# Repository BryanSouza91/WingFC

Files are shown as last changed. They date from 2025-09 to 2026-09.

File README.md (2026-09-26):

# WingFC

> [!WARNING]
> ### ⚠️ REPOSITORY ARCHIVED & SUPERSEDED
> This original TinyGo implementation of WingFC has been archived and is preserved for historical reference.
>
> Active development has transitioned into two dedicated, first-class repositories within the **Ferrox-RC** ecosystem:
> - 🦀 **Firmware:** [**ferrox-rc/wingfc-rs**](https://github.com/ferrox-rc/wingfc-rs) — High-performance, zero-latency bare-metal Rust flight controller firmware for sub-250g wings and UAVs.
> - ⚡ **Hardware:** [**ferrox-rc/wingfc-hardware**](https://github.com/ferrox-rc/wingfc-hardware) — KiCad schematics, 4-layer PCB layouts, 3D mechanical models, and carrier board designs.

### Historical Version 0.3.0 (TinyGo Prototype)

WingFC is a specialized open-source embedded flight controller designed specifically for the rapidly growing sub-250g flying wing FPV (First-Person-View) market. The project's core mission is to provide a reliable, user-friendly, and highly customizable solution for hobbyists and enthusiasts building ultra-lightweight Unmanned Aerial Vehicles (UAVs).

The emphasis on the sub-250g weight class is a direct response to a patchwork of international regulations. Many aviation authorities worldwide, including the Federal Aviation Administration (FAA) in the U.S. and the European Union Aviation Safety Agency (EASA), have established a 250-gram weight threshold as a key regulatory distinction. UAVs below this weight are often considered a lower risk and are exempt from stricter rules, such as mandatory registration, Remote ID requirements, or more complex pilot licensing. By focusing on this market segment, WingFC enables hobbyists to build and fly FPV aircraft that can be legally operated in more places and with fewer bureaucratic hurdles, significantly lowering the barrier to entry for beginners and experienced pilots alike.

Powered by TinyGo, a Go compiler for microcontrollers, WingFC offers a robust and stable software platform. The project provides essential flight control features for elevon-equipped fixed-wing aircraft, including:

- **Stabilization Modes**: Offers flight stabilization to assist pilots, particularly for smooth, cinematic FPV footage and relaxed cruising.

- **Mixing**: Handles the complex mixing of aileron and elevator inputs for a fixed-wing flying wing platform, simplifying the aircraft's setup.

- **Safety Features**: Incorporates failsafe mechanisms to protect the aircraft and others in the event of signal loss.

- **Receiver Protocol Support**: Ensures broad compatibility with popular FPV communication standards, including FlySky's iBus, TBS's CRSF, and the open-source ELRS protocol, which is highly valued for its long-range capabilities and low latency in the FPV community.

The flight controller is engineered for a seamless integration into FPV flying wing airframes like the ZOHD Dart 250G or Alight Wing Aeronautics Flik, a prominent model in this market. The hardware's choice of the Seeed Studio Xiao nRF52840 Sense with an onboard IMU aligns with the project's goal of creating a compact, lightweight, and high-performance control system for these specific FPV drones.

## Getting Started

These instructions will get you a copy of the project up and running on your local machine for development and testing purposes. See deployment for notes on how to deploy the project on a live system.

### Prerequisites

What things you need to install the software and how to install them

```
- Go (TinyGo)
- Supported microcontroller (see docs)
```

### Installing

[Download source code](https://github.com/BryanSouza91/WingFC/releases/tag/v0.3.0)
Extract source code then navigate to the top directory of the source.
```
cd firmware/src
```

Plug in WingFC board via USB-C 

When the filesystem shows up on your computer, flash firmware to your board

```
tinygo flash -target=xiao-ble -tags=<ibus,crsf> firmware/src
```

## Deployment

Add additional notes about how to deploy this on a live system

- Flash the firmware to your supported board
- Connect servos and sensors as described
- Power up and calibrate according to instructions

## Built With

### Software
• [TinyGo](https://tinygo.org/) - Go compiler for microcontrollers  
• [Go](https://golang.org/) - Language
### Hardware
• [Seeed Studio Xiao nrf52840 Sense](https://wiki.seeedstudio.com/XIAO_BLE/) - Xiao nrf52840 Sense microcontroller with onboard IMU

## Supported Receiver Protocols

WingFC supports multiple RC receiver protocols for maximum compatibility:

- **iBus** (FlySky): Supports up to 18 channels (FS-A8S, FS-iA6B)
- **CRSF** (TBS): Supports up to 16 channels
- **ELRS** (open-source): Supports up to 16 channels (uses CRSF build)

## Contributing

Please read [CONTRIBUTING.md](https://github.com/BryanSouza91/WingFC/CONTRIBUTING.md) for details on our code of conduct, and the process for submitting pull requests to us.

## Versioning

We use [SemVer](http://semver.org/) for versioning. For the versions available, see the [tags on this repository](https://github.com/BryanSouza91/WingFC/tags).

## Authors

• Bryan Souza - Initial work - [BryanSouza91](https://github.com/BryanSouza91)
• truglodite - CRSF/ELRS finalization, feature additions - [truglodite](https://github.com/truglodite)

See also the list of [contributors](https://github.com/BryanSouza91/WingFC/contributors) who participated in this project.

## License

This project is licensed under the MIT License - see the [LICENSE](https://github.com/BryanSouza91/WingFC/blob/main/LICENSE) file for details

## Acknowledgments

• Hat tip to anyone whose code was used  
• Inspiration from open-source flight controllers  
• TinyGo and Go communities

## Footer

[GitHub Homepage](https://github.com/)
# WingFC

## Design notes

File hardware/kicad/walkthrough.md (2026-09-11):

# WingFC Flight Controller Hardware Redesign Walkthrough

## Summary of Revisions

Based on feedback, the WingFC flight controller PCB has been comprehensively updated in [`hardware/kicad/`](file:///home/bryansouza/Repos/WingFC/hardware/kicad):

1. **Edge-Mounted North-Facing USB-C Port**:
   - Re-oriented the **Seeed Studio XIAO nRF52840 Sense Plus** (`U1`) by 180° so the USB-C receptacle faces North towards the front edge of the aircraft.
   - Added a dedicated **$12.0\,\text{mm} \times 2.0\,\text{mm}$ recessed access notch** on the front edge of the carrier board.
   - The USB-C connector receptacle now overhangs into free air by $\sim 3.5\,\text{mm}$, ensuring any standard USB-C cable plugs in without mechanical collision against the PCB.

2. **10 Actuator Channels (2 ESCs + 8 Servos)**:
   - Expanded the schematic ([`WingFC.kicad_sch`](file:///home/bryansouza/Repos/WingFC/hardware/kicad/WingFC.kicad_sch)) and netlist ([`WingFC.net`](file:///home/bryansouza/Repos/WingFC/hardware/kicad/WingFC.net)) from 7 channels to **10 channels total**:
     - **`ESC1`** (Motor 1): `D3` (`P0.29`, `PWM0` Ch 0)
     - **`ESC2`** (Motor 2 / Differential Thrust): `D8` (`P1.13`, `PWM0` Ch 1)
     - **`S1`** (Servo 1 - Left Elevon / Aileron): `D0` (`P0.02`, `PWM1` Ch 0)
     - **`S2`** (Servo 2 - Right Elevon / Elevator): `D1` (`P0.03`, `PWM1` Ch 1)
     - **`S3`** (Servo 3 - Rudder / V-Tail): `D2` (`P0.28`, `PWM1` Ch 2)
     - **`S4`** (Servo 4 - Flap / Aux): `D9` (`P1.14`, `PWM1` Ch 3)
     - **`S5`** (Servo 5 - Aux / Pan): `D10` (`P1.15`, `PWM2` Ch 0)
     - **`S6`** (Servo 6 - Flap / Tilt): `D11` (`P0.15`, `PWM2` Ch 1)
     - **`S7`** (Servo 7 - Aux / Arm): `D12` (`P0.19`, `PWM2` Ch 2)
     - **`S8`** (Servo 8 - Payload / Drop): `D13` (`P1.01`, `PWM2` Ch 3)
   - Arranged in a continuous $3 \times 10$ rear block (Signal / +5V / GND) with $2.54\,\text{mm}$ pitch.
   - Silkscreen labels rotated 90° to eliminate text overlap, with clear `S`, `+`, `-` row legends on both flanks.

3. **Outward-Facing JST-SH Connectors**:
   - Rotated both horizontal JST-SH connectors 180°:
     - **`J_RC`** (4-pin JST-SH) on the West (left) edge now has its plug insertion opening facing outward to the left.
     - **`J_GPS`** (6-pin JST-SH) on the East (right) edge now has its plug insertion opening facing outward to the right.
   - Solder pads sit securely on the board copper, while mating cables insert horizontally from outside the board.

4. **Optimized Compact Dimensions**:
   - Target mounting pattern: **$25.5 \times 25.5\,\text{mm}$ M2 pattern** (`H1`..`H4` at $\pm 12.75\,\text{mm}$ from center $(150, 100)$).
   - Board dimensions: **$34.0\,\text{mm}$ wide $\times 40.0\,\text{mm}$ long**.
   - Shortened board length from $41.5\,\text{mm}$ down to $40.0\,\text{mm}$ while fitting all 10 actuator channels.

---

## 3D Board Visualizations

````carousel
![WingFC Top 3D View](/home/bryansouza/.gemini/antigravity/brain/f0d6860b-f0ef-4c42-afec-4011cef9209b/WingFC_3D_top.png)
<!-- slide -->
![WingFC Isometric 3D View](/home/bryansouza/.gemini/antigravity/brain/f0d6860b-f0ef-4c42-afec-4011cef9209b/WingFC_3D_iso.png)
<!-- slide -->
![WingFC Bottom 3D View](/home/bryansouza/.gemini/antigravity/brain/f0d6860b-f0ef-4c42-afec-4011cef9209b/WingFC_3D_bottom.png)
````

---

## Hardware Specifications Table

| Subsystem | Component | Footprint / Package | Location / Layer | Details |
| :--- | :--- | :--- | :--- | :--- |
| **MCU & IMU** | Seeed XIAO nRF52840 Sense Plus | `KiCAD:XIAO-nRF52840-Plus-SMD` | `F.Cu` (Top Center) | 64MHz Cortex-M4F, BLE 5.0, 6-DoF IMU, PDM mic |
| **Actuators** | 10x 1x03 Pin Headers | `Connector_PinHeader_2.54mm` | `F.Cu` (Rear Shelf) | 2x ESCs (`ESC1`, `ESC2`) + 8x Servos (`S1`..`S8`) |
| **RC Receiver** | 4-Pin JST-SH Horizontal | `Connector_JST:JST_SH_SM04B...` | `F.Cu` (West Edge) | 5V, GND, UARTE0 TX/RX (CRSF / iBUS) |
| **GPS & Compass** | 6-Pin JST-SH Horizontal | `Connector_JST:JST_SH_SM06B...` | `F.Cu` (East Edge) | 5V, GND, UARTE1 TX/RX, TWISPI1 SDA/SCL |
| **BEC Power** | Monolithic Power MP2315 | `Package_TO_SOT_SMD:TSOT-23-8` | `B.Cu` (Bottom) | 5V / 2A synchronous step-down (up to 24V in) |
| **Inductor** | Bourns SRN4018 4.7µH | `Inductor_SMD:L_Bourns_SRN4018` | `B.Cu` (Bottom) | Shielded power inductor |
| **Barometer** | Infineon DPS310 | `Package_LGA:Infineon_PG-VLGA-8-1` | `B.Cu` (Bottom) | High-precision pressure sensor on TWISPI1 |
| **Protection** | Littlefuse SMAJ5.0A TVS | `Diode_SMD:D_SMA` | `B.Cu` (Bottom) | 400W transient voltage suppressor on +5V rail |
| **MCU Isolation** | Diodes Inc B0520W Schottky | `Diode_SMD:D_SOD-123` | `B.Cu` (Bottom) | Reverse current protection to +5V_MCU with 10µF cap |
| **Battery Sensing**| 100k / 10k Divider + 100nF | `0603 Metric` | `B.Cu` (Bottom Left) | 11:1 attenuation to SAADC AIN7 (`D16` / `P0.31`) |
| **Mounting** | 4x M2 Holes | `MountingHole_2.2mm_M2` | All Layers | Exact $25.5 \times 25.5\,\text{mm}$ square whoop pitch |

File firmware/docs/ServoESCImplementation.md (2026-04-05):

# WingFC Servo & ESC Control Implementation Report

## Executive Summary
Implemented multi-servo airframe support by upgrading from 2-servo control to 6-servo control with airframe-specific mixing. System now supports elevon flying wings, T-tail configurations, and V-tail configurations through configurable mixer logic.

---

## Architecture Overview

### Servo Output Strategy
- **Servo 1**: Primary aileron control (left elevon / left aileron)
- **Servo 2**: Primary elevator control (right elevon / elevator)
- **Servo 4**: Rudder/V-tail secondary mixing
- **Servo 5**: Secondary aileron (for dual-aileron airframes)
- **Servo 6**: Future expansion (aux control)
- **ESC**: Throttle control (separate PWM peripheral)

### Control Flow
```
RC Input → Kalman Filter (6DoF) → PID Controllers (3-axis)
  ↓
Mixer (airframe-specific) → Servo outputs (1,2,4,5,6)
  ↓
setAllServos() → PWM Hardware → Physical Servos
```

---

## Hardware Configuration Changes

### FC_Hardware Struct Updates
Added six PWM channel ID storage and pin mappings:

```go
type FC_Hardware struct {
	// ... existing fields ...
	pwmCh1, pwmCh2, pwmCh3, pwmCh4, pwmCh5, pwmCh6 uint8  // Channel IDs
	PWM_CH1_PIN machine.Pin  // Aileron Servo
	PWM_CH2_PIN machine.Pin  // Elevator Servo
	PWM_CH3_PIN machine.Pin  // ESC
	PWM_CH4_PIN machine.Pin  // Rudder/V-tail
	PWM_CH5_PIN machine.Pin  // Aileron 2
	PWM_CH6_PIN machine.Pin  // Future use
}
```

### PWM Peripheral Assignment
- **PWM0 (ServoPWM)**: Channels 1, 2, 4, 5, 6 @ 50Hz or 100Hz (servo frequency)
- **PWM1 (ESCPWM)**: Channel 3 @ 50Hz or 400Hz (ESC frequency, configurable)

### Pin Configuration in hardware.go
Each channel (1-6) is configured with retry logic (5 attempts, 100ms intervals):

```go
// Example: Channel configuration pattern
for retries := 0; retries < 5; retries++ {
	ch, err := hw.ServoPWM.Channel(hw.PWM_CH1_PIN)
	if err != nil {
		if retries < 4 {
			time.Sleep(100 * time.Millisecond)
			continue
		}
		return fmt.Errorf("servo PWM channel 1 failed after retries: %w", err)
	}
	hw.pwmCh1 = ch
	break
}
```

---

## Configuration Updates (config.go)

### Airframe Selection
```go
const (
	AIRFRAME_ELEVON = iota
	AIRFRAME_SINGLE_AILERON_T_TAIL
	AIRFRAME_DUAL_AILERON_T_TAIL
	AIRFRAME_SINGLE_AILERON_V_TAIL
	AIRFRAME_DUAL_AILERON_V_TAIL
)
const AIRCRAFT_TYPE = AIRFRAME_ELEVON
```

### Servo Travel Limits
Each servo has configurable min/max pulse widths:
```go
const (
	SERVO1_MIN, SERVO1_MAX = 1100, 1900  // µs
	SERVO2_MIN, SERVO2_MAX = 1100, 1900
	SERVO4_MIN, SERVO4_MAX = 1100, 1900
	SERVO5_MIN, SERVO5_MAX = 1100, 1900
	SERVO6_MIN, SERVO6_MAX = 1100, 1900
)
```

### Servo Reversals
Per-servo reversible output:
```go
const (
	SERVO1_REVERSE = false
	SERVO2_REVERSE = false
	SERVO4_REVERSE = false
	SERVO5_REVERSE = false
	SERVO6_REVERSE = false
)
```

### Yaw Control
```go
const (
	YawChannel = 3  // CH4
	MAX_YAW_RATE_DEG = 100
	yP, yI, yD float32 = 0.5, 0.05, 0.01
)
```

---

## Mixer Implementation (mixer.go - New File)

### ApplyMixer Function
Central airframe configuration logic:

```go
func ApplyMixer(pitchOutput, rollOutput, yawOutput float32) 
	(servo1, servo2, servo4, servo5, servo6 float32)
```

### Supported Configurations

**1. Elevon (Flying Wing) - Default**
```
Left Elevon = Roll + Pitch
Right Elevon = -Roll + Pitch
Yaw servo = Raw yaw output
```

**2. Single Aileron T-Tail**
```
Aileron = Roll
Elevator = Pitch
Rudder = Yaw
```

**3. Dual Aileron T-Tail**
```
Left Aileron = Roll
Elevator = Pitch
Rudder = Yaw
Right Aileron = -Roll
```

**4. Single Aileron V-Tail**
```
Aileron = Roll
Right Surface = Pitch + Yaw
Left Surface = Pitch - Yaw
```

**5. Dual Aileron V-Tail**
```
Left Aileron = Roll
Right Surface = Pitch + Yaw
Left Surface = Pitch - Yaw
Right Aileron = -Roll
```

### Servo Reversals
Applied after mixing:
```go
if SERVO1_REVERSE {
	servo1 = SERVO1_MIN + SERVO1_MAX - servo1
}
// ... same for servos 2, 4, 5, 6
```

---

## Control Loop Updates (main.go)

### Global Variables Added
```go
var (
	yawPID *PIDController
	desiredYawRate float32
)
```

### Hardware Initialization
```go
hw = &FC_Hardware{
	// ... existing ...
	PWM_CH1_PIN: machine.D0,
	PWM_CH2_PIN: machine.D1,
	PWM_CH3_PIN: machine.D2,
	PWM_CH4_PIN: machine.D3,  // New
	PWM_CH5_PIN: machine.D4,  // New
	PWM_CH6_PIN: machine.D5,  // New
}
```

### PID Initialization
```go
yawPID = NewPIDController(yP, yI, yD)
```

### Stabilized Flight Loop
Three-axis control with airframe-specific mixing:

1. **Sensor Fusion**
   ```go
   kf.Predict(imuData.GyroX, imuData.GyroY, imuData.GyroZ)
   kf.Update(imuData.Pitch, imuData.Roll)
   ```

2. **RC Input Mapping**
   ```go
   desiredPitchRate = mapRange(Channels[ElevatorChannel], ...)
   desiredRollRate = mapRange(Channels[AileronChannel], ...)
   desiredYawRate = mapRange(Channels[YawChannel], ...)
   ```

3. **PID Control**
   ```go
   pitchOutput = pitchPID.Update(pitchError, dt) * PID_WEIGHT
   rollOutput = rollPID.Update(rollError, dt) * PID_WEIGHT
   yawOutput = yawPID.Update(yawError, dt) * PID_WEIGHT
   ```

4. **Airframe Mixing**
   ```go
   servo1, servo2, servo4, servo5, servo6 := ApplyMixer(pitchOutput, rollOutput, yawOutput)
   ```

5. **Output Mapping & Constraints**
   ```go
   servo1 = mapRange(servo1, -MAX_ROLL_RATE, MAX_ROLL_RATE, MIN_PULSE_WIDTH_US, MAX_PULSE_WIDTH_US)
   servo1 = constrain(servo1, SERVO1_MIN, SERVO1_MAX)
   // ... for all servos
   ```

6. **Hardware Output**
   ```go
   setAllServos(uint32(servo1), uint32(servo2), uint32(servo4), uint32(servo5), uint32(servo6))
   ```

---

## Helper Functions (helpers.go)

### New: setAllServos()
Controls all six servo channels with PWM duty cycle calculation:

```go
func setAllServos(servo1, servo2, servo4, servo5, servo6 uint32) {
	if hw == nil || hw.ServoPWM == nil {
		return
	}
	
	top_value := hw.ServoPWM.Top()
	
	// Calculate duty cycle for each servo
	// duty = (pulse_width_µs * 1000 * PWM_TOP) / ServoPeriod
	duty1 := uint32(uint64(servo1) * 1000 * uint64(top_value) / uint64(hw.ServoPeriod))
	hw.ServoPWM.Set(hw.pwmCh1, duty1)
	
	// ... repeat for servo2, servo4, servo5, servo6
}
```

### Legacy: setServo()
Preserved for backward compatibility, wraps setAllServos():

```go
func setServo(leftPulse, rightPulse uint32) {
	setAllServos(leftPulse, rightPulse, NEUTRAL_RX_VALUE, NEUTRAL_RX_VALUE, NEUTRAL_RX_VALUE)
}
```

### setESC()
Unchanged - remains separate PWM peripheral (PWM1)

---

## Kalman Filter (kalman.go)

### 3x3 Matrix Implementation
Full 3-axis attitude estimation:

```go
type KalmanFilter struct {
	X *Matrix3x1  // State: [pitch, roll, yaw]
	P *Matrix3x3  // Covariance
	Q *Matrix3x3  // Process noise
	R *Matrix2x2  // Measurement noise (accel: pitch, roll)
	F *Matrix3x3  // State transition
	H *Matrix3x2  // Observation matrix (3 states → 2 measurements)
	dt float32
}
```

### State Propagation
All three axes predicted from gyroscope:
```go
func (kf *KalmanFilter) Predict(gyroX, gyroY, gyroZ float32) {
	gyroVector.Set(0, 0, gyroY*kf.dt)   // Pitch rate
	gyroVector.Set(1, 0, gyroX*kf.dt)   // Roll rate
	gyroVector.Set(2, 0, gyroZ*kf.dt)   // Yaw rate
	kf.X = kf.X.Add(gyroVector)
	// P_pred = F*P*F^T + Q
}
```

### Measurement Update
Only pitch/roll updated from accelerometer (yaw prediction-only):
```go
func (kf *KalmanFilter) Update(accelPitch, accelRoll float32) {
	// H is 3x2: updates rows 0-1 (pitch, roll) only
	// Row 2 (yaw) remains unmeasured
	// Ready for magnetometer: just modify H[2,*] and R when available
}
```

---

## Testing & Validation Checklist

- [ ] Hardware PWM channels 1-6 initialize without errors
- [ ] Each servo responds to independent control inputs
- [ ] Airframe mixer produces correct output ratios for each configuration
- [ ] Servo reversals apply correctly
- [ ] Servo constraints prevent over-travel
- [ ] ESC throttle control remains independent
- [ ] Kalman filter accepts all three gyro inputs
- [ ] Manual mode still functions (legacy servo mapping)
- [ ] Failsafe centers all servos to neutral
- [ ] No servo glitches on mode transitions

---

## Performance Impact

### CPU Cycles
- New matrix operations: ~3x3 multiply/invert adds ~200-300 cycles per iteration
- Mixer logic: ~50 cycles
- Additional servo calculations: ~200 cycles
- **Total per-loop overhead**: ~500 cycles on 200Hz loop = minimal impact

### Memory
- 3x3 Kalman matrices: ~72 bytes (vs. 2x2: 32 bytes)
- Mixer outputs: +24 bytes (3 extra servos)
- **Total additional RAM**: ~100 bytes (acceptable on nRF52840)

### Latency
- No impact to 200Hz control loop latency
- Servo outputs update synchronously with PID calculations

---

## Future Enhancements

### 9DoF Magnetometer Support
- Replace `Update()` call with magnetometer heading measurement
- Modify H matrix row 2 from [0,0,0] to [0,0,1]
- Extend R from 2x2 to 3x3
- No API changes required

### Advanced Mixers
- Helicopter swashplate mixing
- Quadcopter motor mixing
- VTOL motor coordination

### Per-Servo Tuning
- Individual servo response curves
- Dynamic trim adjustment via RC
- Servo health monitoring & diagnostics

---

## Files Modified/Created

| File | Status | Changes |
|---|---|---|
| `config.go` | Modified | Added airframe selection, servo limits, reversals, yaw constants |
| `hardware.go` | Modified | Added 5 servo channels (1,2,4,5,6), retry logic, PWM config |
| `main.go` | Modified | Added yaw PID, Kalman 3-axis predict, updated control loop |
| `helpers.go` | Modified | New `setAllServos()`, legacy `setServo()` wrapper |
| `kalman.go` | Modified | Upgraded to 3x3 matrices, 3-axis support |
| `mixer.go` | **Created** | New file with airframe mixing logic |

---

## Summary

This implementation provides a scalable, production-ready servo control system supporting multiple airframe types while maintaining clean separation of concerns:

- **Configuration**: Airframe type, servo limits, reversals all in config.go
- **Mixing Logic**: Dedicated mixer.go handles airframe-specific transformations
- **Hardware Abstraction**: PWM layer isolated in hardware.go
- **Control**: Main.go coordinates sensor fusion, PID, and servo output
- **Future-Ready**: 3x3 Kalman accommodates 9DoF without refactoring

The modular architecture allows quick addition of new airframe types by adding new mixer cases without touching core control logic.

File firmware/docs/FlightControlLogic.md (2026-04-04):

# **WingFC Flight Control Logic (v0.3.0)**

## **Overview**

The WingFC firmware utilizes a 200Hz (5ms) control loop to manage flight stabilization for sub-250g fixed-wing aircraft. It integrates sensor fusion via a Kalman filter and utilizes PID controllers for pitch and roll stabilization. Kalman filters and Matrix operations are ready for 3 state stabilization.

## **System Flowchart**

The following logic represents the core operational flow of the main.go entry point.

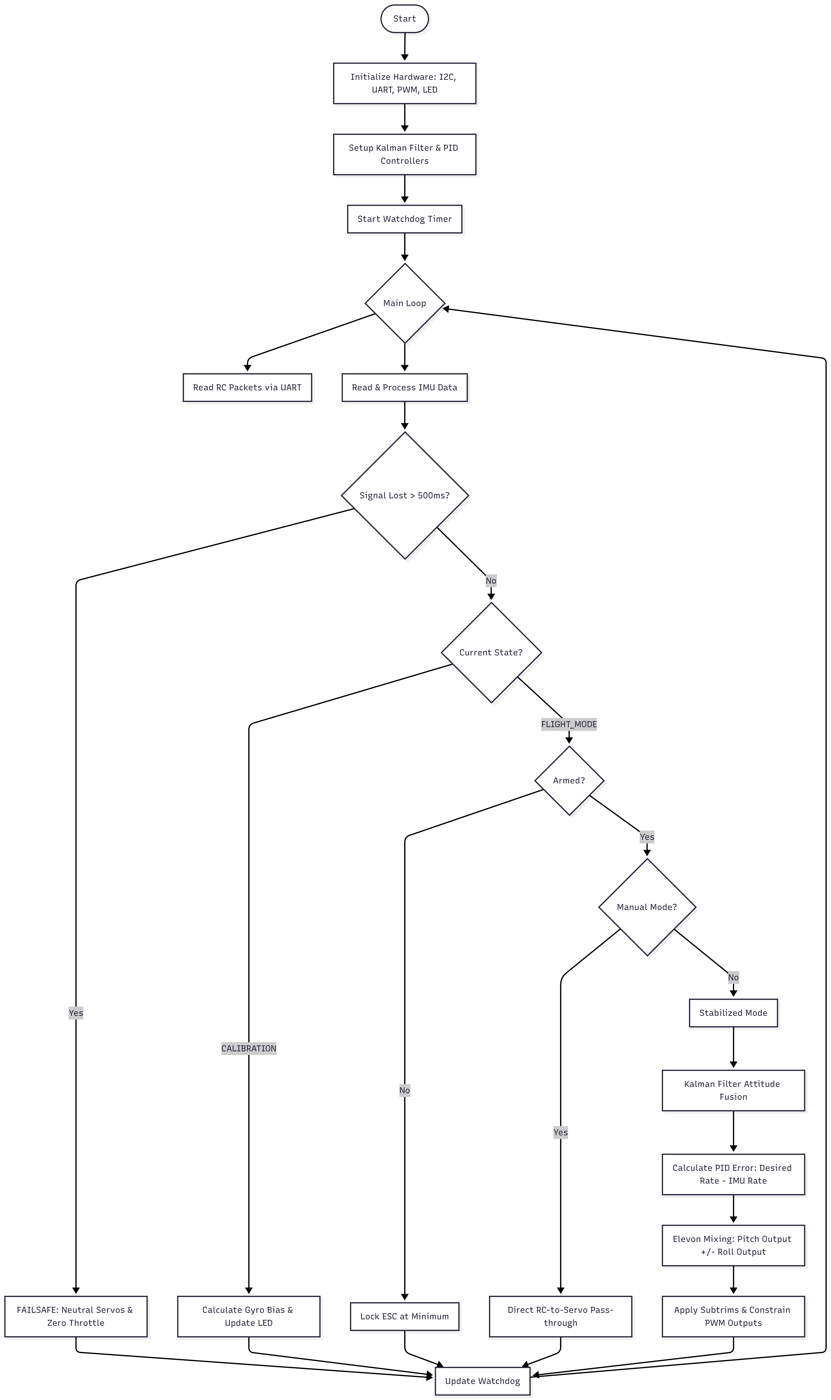
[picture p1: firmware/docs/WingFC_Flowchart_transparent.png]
WingFC Flowchart


## **Logic Breakdown**

### **1. Initialization & Safety**

* **Hardware Setup:** Configures the Seeed Studio Xiao nRF52840 Sense pins for I2C (LSM6DS3TR-C IMU/Magnetometer), UART (IBUS/CRSF/ELRS), UART2 (GPS), and PWM (Servos/ESC).  
* **Watchdog:** A 1-second hardware watchdog triggers a system reset if the main loop hangs.

### **2. State Machine**

* **CALIBRATION:** Finds gyro bias while stationary to prevent PID "drift." A magnetometer is highly recommended for yaw stabilization.   
* **FAILSAFE:** Centers surfaces and cuts power if connection is lost for >500ms.  
* **FLIGHT_MODE:** Monitors arming status and toggles between stabilized and manual control.

### **3. Stabilized Control Loop (200Hz)**

* **Sensor Fusion:** Kalman filter fuses accelerometer and gyroscope data for a stable attitude estimate.  
* **PID Control:** Maps RC stick positions to a "Desired Rate" and calculates the error against the "Actual Rate" from the IMU.  
* **Elevon Mixing:** Mixes pitch and roll outputs to drive left and right elevons.
* **Airframe Mixing:** Will add ApplyMixer() function to calculate proper mixing for various airframes.

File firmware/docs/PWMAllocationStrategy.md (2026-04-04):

# **nRF52840 PWM Allocation (XIAO BLE Sense & Sense Plus)**

The nRF52840 features 4 independent PWM instances (PWM0-3). Each instance has 4 channels that **must share the same frequency.** This is a critical constraint for flight controllers using a mix of 50Hz servos and 400Hz+ ESCs.

## **1. Optimal Allocation for WingFC (Standard & Plus)**

To ensure stable flight, keep servos and ESCs on separate PWM instances.

| Component | Pin | Instance | Frequency | Notes |
| :---- | :---- | :---- | :---- | :---- |
| **Aileron Servo** | D0 | machine.PWM0 | 50 Hz | Standard & Plus |
| **Elevator Servo** | D1 | machine.PWM0 | 50 Hz | Standard & Plus |
| **ESC (Throttle)** | D2 | machine.PWM1 | 400 Hz+ | Supports OneShot/DShot |

## **2. Expansion Scenarios for "Sense Plus"**

The **XIAO Sense Plus** breaks out more pins, allowing for complex airframes without sacrificing I2C or UART with the addition of UART2.

### **The "Full House" Airplane (Servos + ESC)**

Cluster all servos on **PWM0** to save other instances for high-speed tasks.

* **D0:** Aileron (PWM0)  
* **D1:** Elevator (PWM0)  
* **D3:** Rudder (PWM0)  
* **D7:** Flaps (PWM0) — *Note: On Plus, D7 is available as GPIO however it will be used for UART2*  
* **D2:** ESC (PWM1) — *Independent high-speed throttle*

## **3. Plus-Specific Considerations**

The XIAO Sense Plus introduces features that impact how we handle the control loop:

* **Battery Management:** The Plus version includes a built-in battery charging chip. It can monitor battery voltage via the internal P0.31 (VBAT) pin using ADC to implement a low-voltage battery failsafe.  
* **Additional GPIO:** While the standard Sense has 11 GPIOs, the Plus provides more routing options, allowing for the RC Receiver (UART) to be moved to the extra pins if D6/D7 are needed for PWM.  
* **Flash Memory:** The Plus often features more QSPI Flash, which is ideal for "Blackbox" flight logging. Need to write the driver for TinyGo before we go down this path.

## **4. TinyGo Configuration**

Ensure the periods are set explicitly during hardware initialization to prevent frequency clashing:
```Go  
// 50Hz for traditional analog/digital servos
hw.ServoPWM.Configure(machine.PWMConfig{
    Period: machine.GHz * 1 / SERVO_PWM_FREQUENCY})

// 400Hz for standard ESCs (for smoother throttle response)
hw.ESCPWM.Configure(machine.PWMConfig{
    Period: machine.GHz * 1 / ESC_PWM_FREQUENCY})   
```
## **5. Hardware Guardrails**

* **Avoid D6/D7 (Standard):** These are UART pins used for the RC Receiver (CRSF/ELRS/IBUS). On the Plus, check your specific pin map if you use GPS which will use the secondary UART.  
* **Reserve D4/D5:** Keep these free for I2C. We will be adding Magnetometer and will likely want to add a Barometer (BMP280/SPL06) for altitude hold.  
* **Internal IMU:** The LSM6DS3TR-C is on an internal I2C bus. Do not assign PWM to the internal SDA/SCL pins or the IMU will disconnect.

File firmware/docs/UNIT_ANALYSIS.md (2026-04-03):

# WingFC Unit Analysis & Consistency Audit

## Current State: Units in the Control Loop

### 1. **Raw Sensor Data → Base Units**

| Data | Raw Format | Conversion | Base Unit | Location |
|---|---|---|---|---|
| **Accelerometer** | Raw ADC counts | × `microGToMS2` = × 9.80665e-6 | **[m/s²]** | `helpers.go` line 19-21 |
| **Gyroscope** | Raw ADC counts | × `microDPSToRadS` = × π/(180e6) | **[rad/s]** | `helpers.go` line 22-24 |

✅ **Conversion correct:** LSM6DS3 outputs microG and microDPS; conversions are mathematically valid.

---

### 2. **Attitude Estimation from Accelerometer**

```go
// imu.go lines 21-27
Pitch = atan2(-AccelX, sqrt(AccelY² + AccelZ²))  // → [radians]
Roll = atan2(AccelY, AccelZ)                     // → [radians]
```

| Data | Input | Output | Notes |
|---|---|---|---|
| **Pitch** | AccelX [m/s²] | [radians] | atan2 always outputs [radians] |
| **Roll** | AccelY, AccelZ [m/s²] | [radians] | atan2 always outputs [radians] |

✅ **Correct:** Acceleration vectors → angle via trigonometry produces radians.

---

### 3. **Desired Rate from RC Receiver**

```go
// main.go lines 210-211
desiredPitchRate = mapRange(RC_input, MIN_RX_VALUE, MAX_RX_VALUE, 
                             -MAX_PITCH_RATE, MAX_PITCH_RATE)
desiredRollRate = mapRange(RC_input, MIN_RX_VALUE, MAX_RX_VALUE, 
                            -MAX_ROLL_RATE, MAX_ROLL_RATE)
```

Where:
```go
// main.go lines 57-58
MAX_PITCH_RATE = MAX_PITCH_RATE_DEG * math.Pi / 180  // [rad/s]
MAX_ROLL_RATE = MAX_ROLL_RATE_DEG * math.Pi / 180   // [rad/s]
```

| Data | Output | Units | Notes |
|---|---|---|---|
| **Desired Pitch Rate** | [-MAX_PITCH_RATE, MAX_PITCH_RATE] | **[rad/s]** | ✓ Correct |
| **Desired Roll Rate** | [-MAX_ROLL_RATE, MAX_ROLL_RATE] | **[rad/s]** | ✓ Correct |

✅ **Correct:** RC input scales to rate setpoint in radians/second.

---

### 4. **Kalman Filter Input/Output**

```go
// main.go lines 207-208
kf.Predict(imuData.GyroX, imuData.GyroY)        // Both [rad/s] ✓
kf.Update(imuData.Pitch, imuData.Roll)          // Both [radians] ✓
```

**Kalman State:**
```go
// kalman.go
X *Matrix2x1  // [pitch_angle, roll_angle] in [radians]
```

**Predict Step:**
```go
// kalman.go Predict()
gyroVector.Set(0, 0, gyroY * kf.dt)  // [rad/s] × [s] = [rad] ✓
gyroVector.Set(1, 0, gyroX * kf.dt)  // [rad/s] × [s] = [rad] ✓
```

**Update Step:**
```go
// kalman.go Update()
z.Set(0, 0, accelPitch)  // [radians] ✓
z.Set(1, 0, accelRoll)   // [radians] ✓
```

✅ **Correct:** Kalman filter consistently uses [radians] for angles and [rad/s] for rates.

---

### 5. **PID Controller - UNIT MISMATCH DETECTED ⚠️**

```go
// main.go lines 223-224
pitchError := desiredPitchRate - imuData.GyroY  // [rad/s] - [rad/s] = [rad/s] ✓
rollError := desiredRollRate - imuData.GyroX    // [rad/s] - [rad/s] = [rad/s] ✓

// main.go lines 227-228
pitchOutput := pitchPID.Update(pitchError, dt) * PID_WEIGHT
rollOutput := rollPID.Update(rollError, dt) * PID_WEIGHT

// pid.go lines 21-31
proportional := pid.Kp * currentError           // [Kp_units] × [rad/s] = ???
integral := pid.Ki * (currentError * dt)        // [Ki_units] × [rad] = ???
derivative := pid.Kd * (currentError / dt)      // [Kd_units] × [rad/s²] = ???
```

**PROBLEM:** The PID gain units (Kp, Ki, Kd) are **not documented** and their relationship to the output is **ambiguous**.

---

### 6. **Control Output to PWM - CRITICAL MISMATCH ⚠️⚠️⚠️**

```go
// main.go lines 234-235
leftElevon = mapRange(float64(leftElevon), -MAX_ROLL_RATE, MAX_ROLL_RATE, 
                      MIN_PULSE_WIDTH_US, MAX_PULSE_WIDTH_US)
```

**BUG:** This assumes:
```
PID_output ∈ [-MAX_ROLL_RATE, MAX_ROLL_RATE]
            ∈ [rad/s]
```

But what units is `pitchOutput` actually in? **Not defined!**

If Kp = 1.0 (dimensionless), then:
```
pitchOutput = 1.0 × [rad/s] = [rad/s]  ✓ Would work
```

But if Kp = 0.5, then:
```
pitchOutput = 0.5 × [rad/s] = 0.5 × [rad/s]  (what does this mean?)
```

---

## Summary: Unit Consistency Issues

| Component | Status | Issue |
|---|---|---|
| Sensor → SI units | ✅ OK | Correct conversions, well-defined |
| Accelerometer → Angles | ✅ OK | Trigonometry → radians (correct) |
| RC → Desired Rates | ✅ OK | Maps to [rad/s] (correct) |
| Kalman Filter | ✅ OK | Consistent: [radians] for angles, [rad/s] for rates |
| PID Error Input | ✅ OK | [rad/s] - [rad/s] = [rad/s] (correct) |
| **PID Gain Units** | ❌ **UNDOCUMENTED** | Kp, Ki, Kd units unknown |
| **PID Output Units** | ❌ **AMBIGUOUS** | Should be [rad/s] but not enforced |
| **Output Mapping** | ⚠️ **DEPENDS ON PID** | Assumes pidOutput ∈ [rad/s] |

---

## Recommendations

### 1. **Document PID Gain Units (Required)**

Add comments to PID controller:
```go
type PIDController struct {
	// Kp: Proportional gain [dimensionless]
	// Output units: [rad/s] when error is [rad/s]
	// Example: error [rad/s] × Kp=1.0 → output [rad/s]
	Kp float64
	
	// Ki: Integral gain [1/s]
	// Converts integrated error [rad] to [rad/s]
	// Example: 100 rad × Ki=0.01 [1/s] → 1.0 [rad/s]
	Ki float64
	
	// Kd: Derivative gain [dimensionless]
	// Converts rate of error [rad/s²] to [rad/s]
	// Example: 10 [rad/s²] × Kd=0.1 → 1.0 [rad/s]
	Kd float64
}
```

### 2. **Add Type-Safe Unit Wrapper (Optional, More Work)**

```go
type RadiansPerSecond float64
type Radians float64

type PIDController struct {
	Kp, Ki, Kd float64
	prevError  RadiansPerSecond
	integral   Radians
}

func (pid *PIDController) Update(currentError RadiansPerSecond, dt float64) RadiansPerSecond {
	// Compiler enforces correct units
	proportional := RadiansPerSecond(pid.Kp) * currentError
	// ...
}
```

### 3. **Add Validation Function**

```go
// Check PID gains are reasonable
func ValidatePIDGains(kp, ki, kd float64) error {
	// For rate control with [rad/s] error:
	// Kp should be dimensionless (typically 0.1-5.0)
	// Ki should be [1/s] (typically 0.01-0.5)
	// Kd should be dimensionless (typically 0.01-1.0)
	
	if kp < 0 || ki < 0 || kd < 0 {
		return fmt.Errorf("PID gains must be positive")
	}
	if kp > 10 || ki > 5 || kd > 5 {
		return fmt.Errorf("PID gains seem excessive, check units")
	}
	return nil
}
```

### 4. **Add Debug Output with Units**

```go
// main.go - for debugging
if loopCount%100 == 0 {
	println("[UNITS_DEBUG]")
	println("  DesiredRate [rad/s]:", desiredPitchRate)
	println("  GyroRate [rad/s]:", imuData.GyroY)
	println("  Error [rad/s]:", pitchError)
	println("  PIDOutput [???]:", pitchOutput)  // WHAT UNITS??
	println("  MapRange in: [-MAX_ROLL_RATE:", -MAX_ROLL_RATE, "]")
}
```

---

## Next Steps

1. **Immediate:** Add documentation comments specifying Kp/Ki/Kd units
2. **Short-term:** Add validation function
3. **Long-term:** Consider type wrappers for compile-time unit safety

Would you like me to implement these fixes?

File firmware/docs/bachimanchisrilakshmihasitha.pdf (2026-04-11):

# Attitude Estimation using Madgwick Filter on 6-DoF IMU

Ankush Singh Bhardwaj
abhardwaj@wpi.edu

Sri Lakshmi Hasitha Bachimanchi
sbachimanchi@wpi.edu

Anuj Pradeep Pai Raikar
apairaikar@wpi.edu

Abstract—This project presents the implementation of Madgwick filter to estimate the 3D orientation of the IMU (ArduIMU+ V2) by reading the acceleration and the gyroscope values given by it. A complementary filter is also implemented to fuse the values from the accelerometer and the gyroscope to obtain the orientation. The orientation obtained by the filters is then compared with the ground truth from the vicon motion capture system.

I. IMPLEMENTATION
A. Reading and Appropriating the Data
The data is obtained from six degree IMU, 3-axis gyroscope and 3-axis accelerometer fitted on a drone. The orientation of the IMU recorded from the VICON motion capture is also provided. The data for each correspondence is provided in a .mat file. The IMU data exists as:

[ax, ay, az, wz, wx, wy]

The VICON data meanwhile stores the timestamps ts and the orientation in a 3x3 Rotation matrix denoting Z-Y-X Euler angles for N time instances. The parameter values for the IMU are also provided in a 2x3 vector containing the Scale and Bias values.

The acceleration has been converted into m/s²
. The formula
implemented in the code is:

a¯ = (a · scale + bias) · g

The angular rates have been converted into rad/s⁻¹ .

ω¯ =

3300
1023

·

π
180
- (ω − bg)

The bias for angular rate conversion is obtained by calculating the average of the first couple hundred values of each angular rate from the IMU data.

B. Implementation of the Methods to estimate Orientations Methodology
We use four methods to estimate the orientation of the IMU. The first method uses only the gyroscope readings for attitude estimation, while the second uses the accelerometer readings. We also implement a Complementary filter and Madgwick filter by fusing the readings from both gyroscope

Fig. 1. 3D Rotation

and accelerometer.

Rotation Matrix using R-P-Y Euler Angles Method The attitude is calculated from the roll, pitch and yaw rate by using the 3D rotation matrix formula notation in Fig 1.

1) Orientation From Gyroscope Measurements:

Using Integration:

- The function iterates through the IMU timestamps and gyroscope measurements obtained from the IMU data.
- For each timestamp, the time difference between the current and previous timestamps is calculated.
- The orientations are updated using the roll, pitch, and yaw angles calculated above w x, w y, w z.
2) Orientation from Accelerometer Measurements:
- The second method used only the accelerometer readings for attitude estimation.
- The orientation is returned as well as the roll, pitch and yaw values stored as a vector are returned.
- The formula is used keeping in mind IMU is only rotating and that the acceleration due to gravity is in the Z-axis.

Roll , ϕ = tan⁻¹
p

ay
a

2
x + a

2
z

!

Pitch , θ = tan⁻¹

q

−ax

a

2
y + a

2
z

Yaw , ψ = tan⁻¹

q
a

2
x + a

2
y
az
3) Complementary Filter:
- We low pass the accelerometer measurement data as described below. The alpha for Low Pass filter is taken as 0.2

Fig. 2. Accelerometer LPF

- We high pass the gyroscope measurement data as described below. The alphs for High Pass filter is taken as 0.2.

Fig. 3. Gyroscope HPF

- The two measurements are fused into one using a α value that weighs the two. The alpha for complementary filter is taken as 0.5.
- The output orientation is stored for plotting.
4) Madgwick Filter:

The newer method used for the above estimated attitudes is Madgwick filter. This filter formulates the problem in quaternion space.
- We begin by calculating the readings for orientation obtained only from the gyroscope and only from the accelerometer, in the quaternion notation.
- Normalise the quaternion notation orientation we calculated in the above steps using formula in Fig 2.
- The second step is to perform the orientation increments from the accelerometer. Let our initial estimate begin at the quaternion [1 0 0 0].

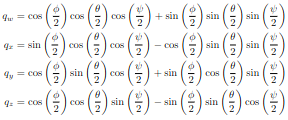
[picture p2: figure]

Fig. 4. Euler Angles to Quaternion Conversion

- We calculate the orientation estimate from the gyroscope using the formula below.

I
W q˙ ω,t+1 =

1
2

Wqˆest,t ⊗

0

Iωt+1
(1)
- The function f formulated for the compliance of the values and the Jacobian (J) are calculated and their product is used to get our gradient from our previous estimate.

∇f

I
W qˆest,t,

W gˆ,

Iaˆt+1

= J

T

I
W qˆest,t,

W gˆ
∇f

I
W qˆest,t,

W gˆ,

Iaˆt+1

(2)

where

J

I
W qˆest,t,

W gˆ
=

−2q3 | 2q4 | −2q1 | 2q2
2q2 | 2q1 | 2q4 | 2q3
0 | −4q2 | −4q3 | 0

and

f

I
W qˆest,t,

W gˆ,

Iaˆt+1
=

2 (q2q4 − q1q3) − ax

2 (q1q2 + q3q4) − ay

2

1
2 − q

2
2 − q

2/3
− az

(3)

- Update Step: The normalised gradient is multiplied by β and that product is subtracted from the new gyroscope measurement estimate.

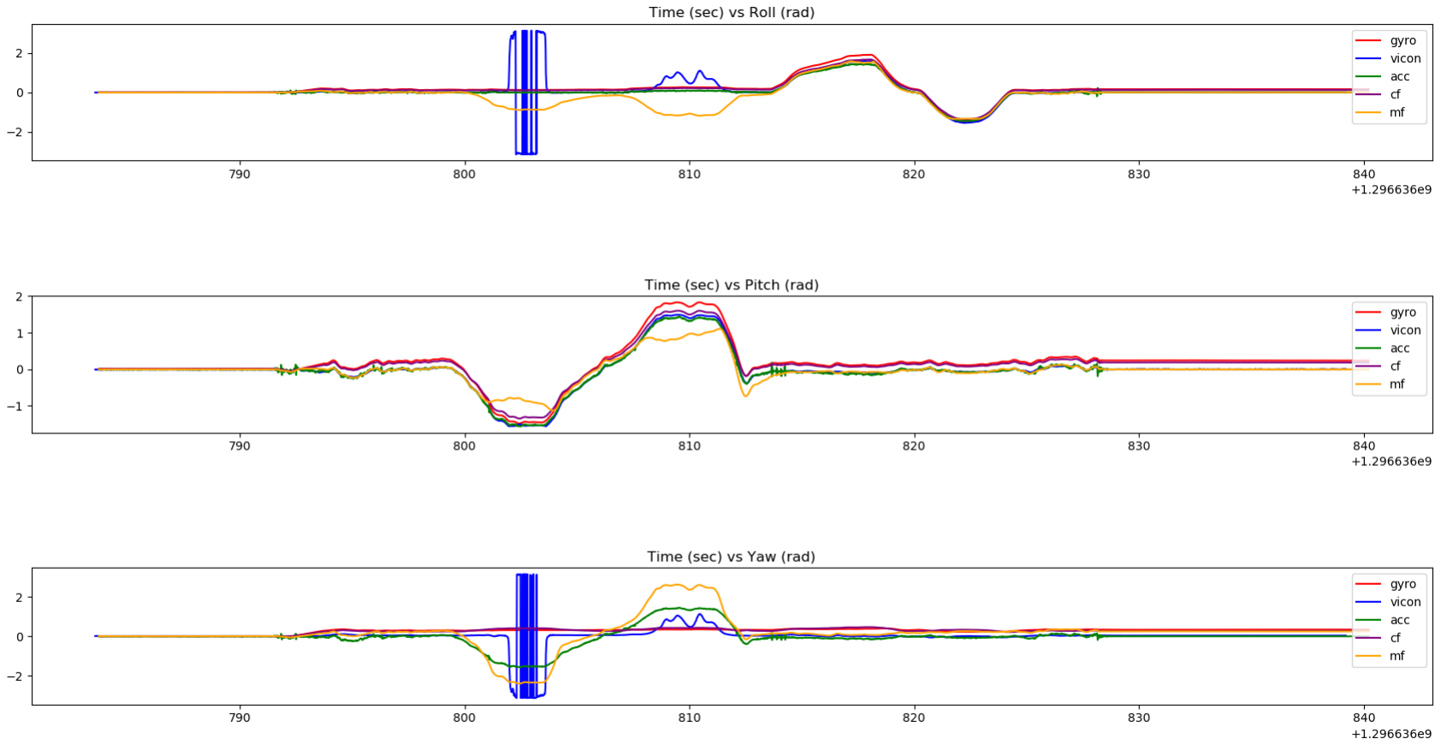
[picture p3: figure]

The term beta is the trust ratio between the accelerometer and gyroscope values and is set to 0.09.(Manually tuned)

- Calculate use the product of the update step and the difference in the time step.
- The new estimate is given as the sum of the normalised previous estimate and the product above. See the formula below.

I
W q˙ est,t+1 =

I
W q˙ ω,t+1 +

I
W q∇,t+1

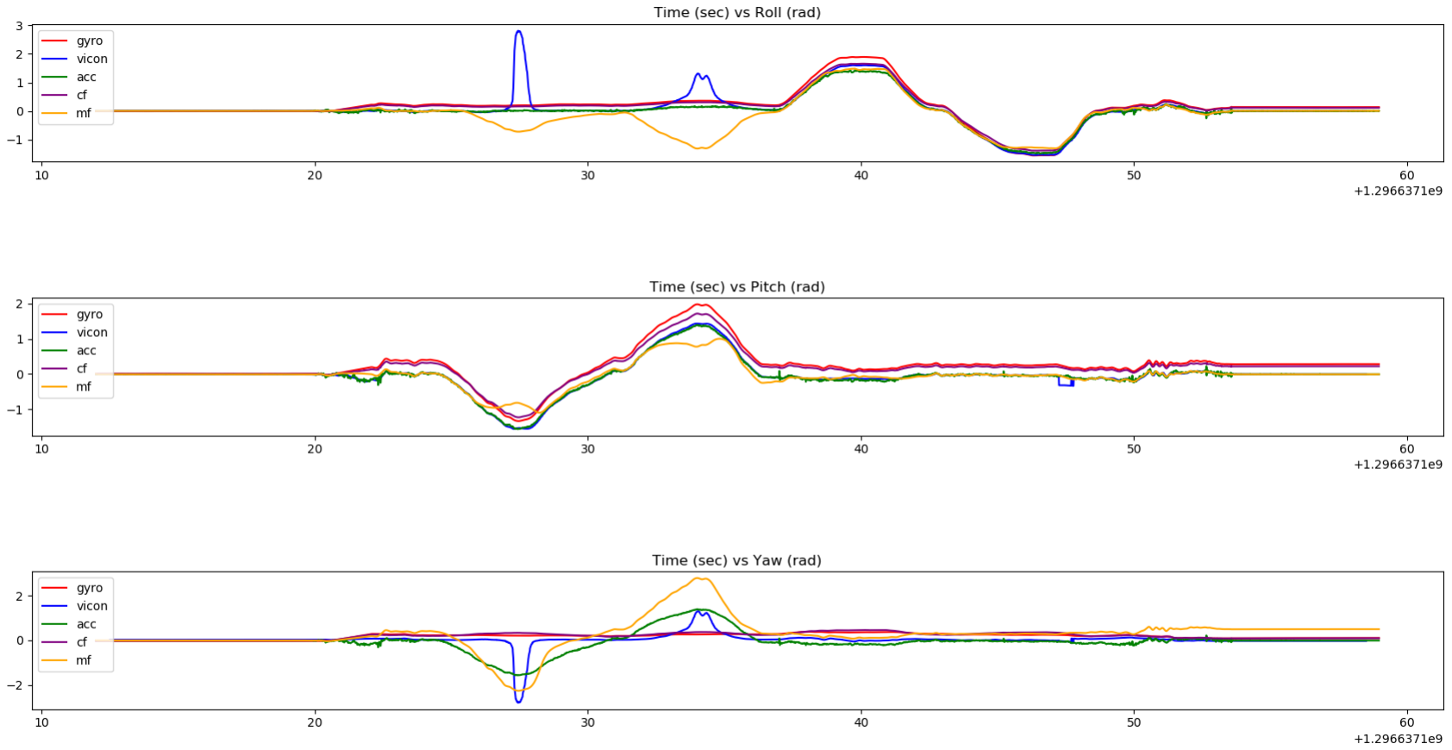
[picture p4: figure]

- Repeat the steps at each time instant.
- Estimates calculated at each time instant are converted to the Euler angle representation.

sin(pitch) = 2 · (w · y − z · x)

pitch =

π
2

if sin(pitch) > 0

−

π
2

if sin(pitch) < 0

arcsin(sin(pitch)) otherwise

sin(yaw + pitch) = 2 · (w · z + x · y)

cos(yaw + pitch) = 1 − 2 · (y

2 + z

2
)

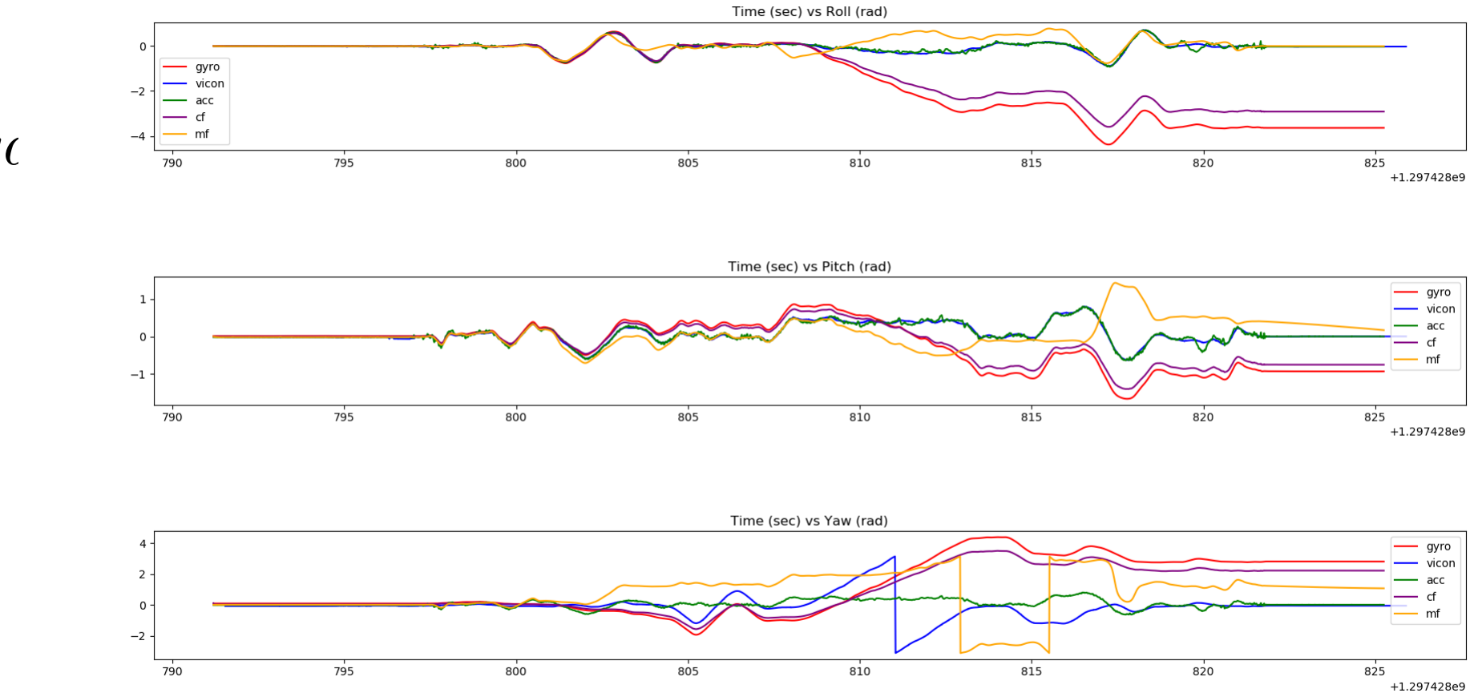
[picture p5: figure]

yaw = arctan 2(sin(yaw + pitch), cos(yaw + pitch))

sin(roll) = 2 · (w · x − y · z)

roll =

π
2

if sin(roll) > 0

−

π
2

if sin(roll) < 0

arcsin(sin(roll)) otherwise

II. RESULTS
The beta and alpha values for the filters are tuned such that it matches closely the VICON data. Please see the figures attached here. The link to the videos obtained after running the rotplot.py and can be referred to with the name of the data set where 1-6 is for the given the data set and 7-10 is the test sets.
LINK: https://drive.google.com/drive/folders/1diiW5OvQsam4cf5huYon-TeDV9fEZU3

III. REFERENCES
1 https://nitinjsanket.github.io/tutorials/attitudeest/2 ENAE788M: YouTube

Fig. 5. Plots for Dataset 1

Fig. 6. Plots for Dataset 2

Fig. 7. Plots for Dataset 3

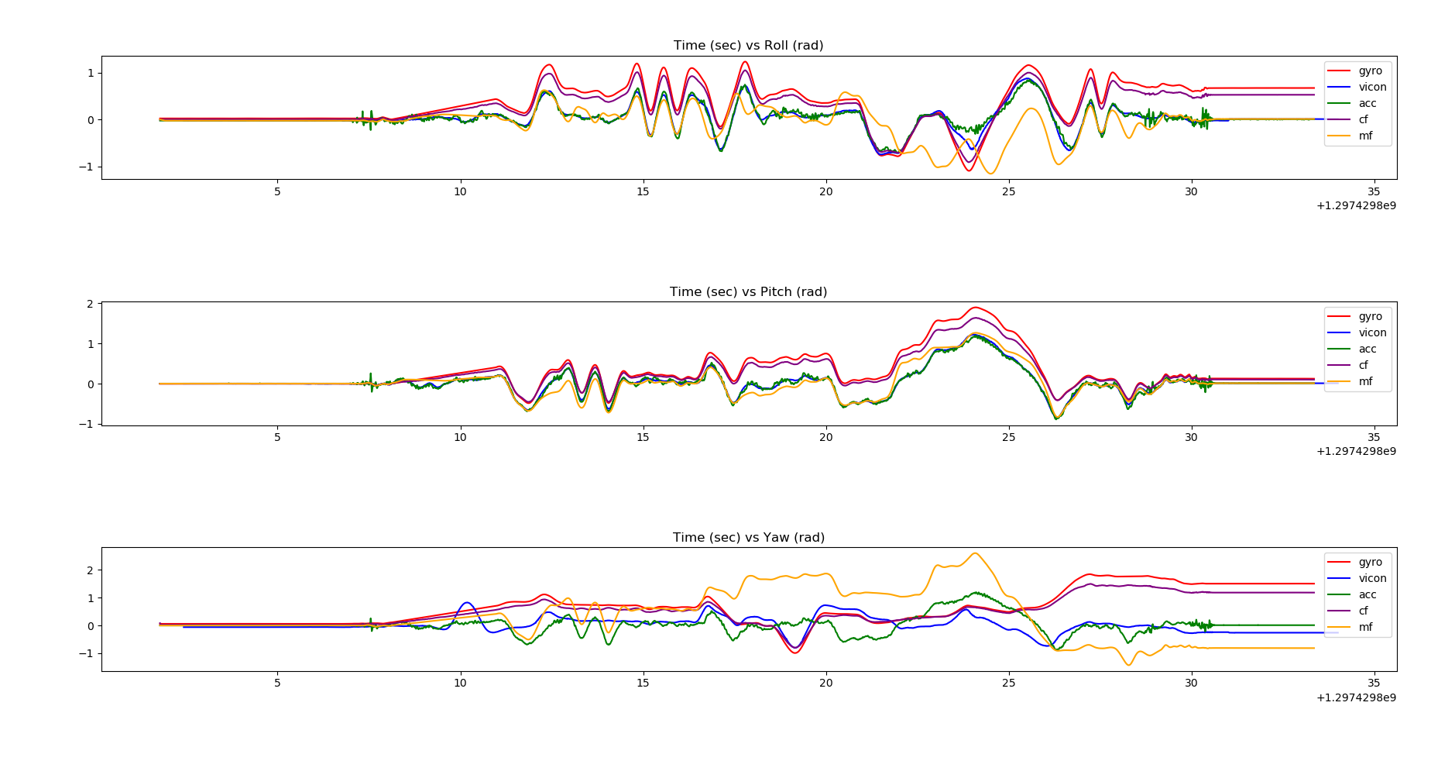
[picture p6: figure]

Fig. 8. Plots for Dataset 4

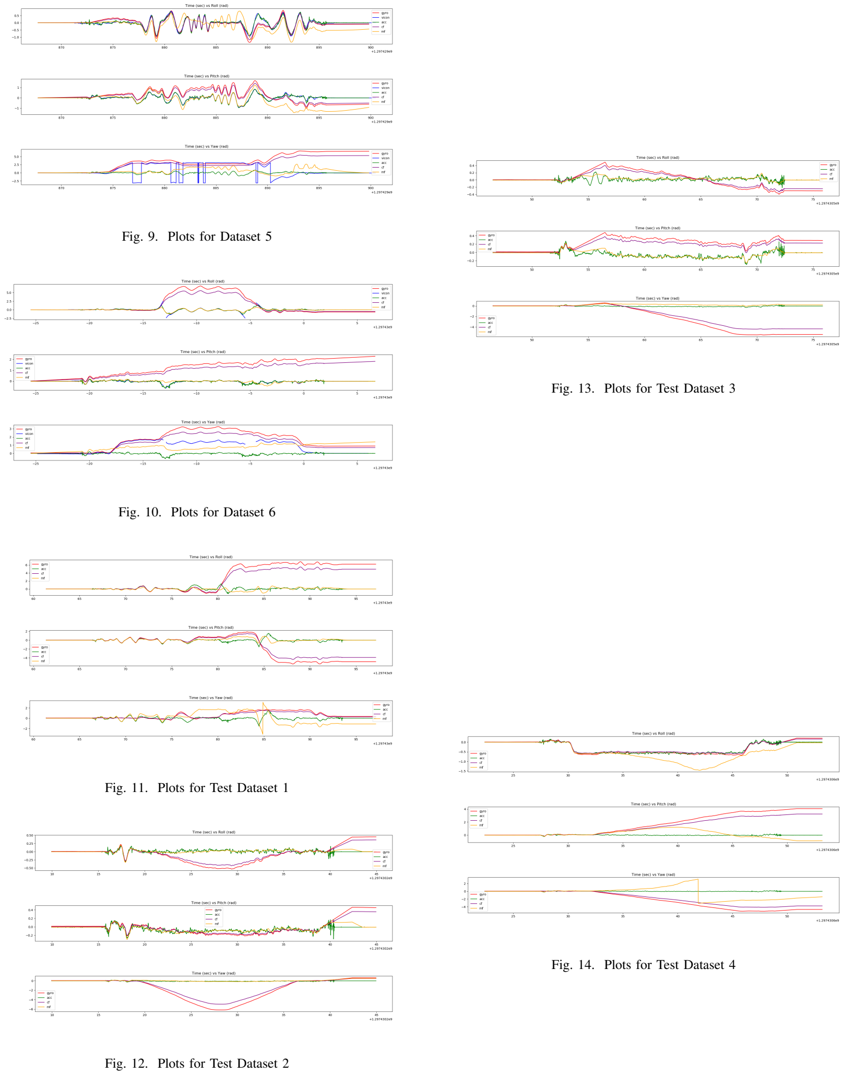
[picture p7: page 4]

Fig. 9. Plots for Dataset 5

Fig. 10. Plots for Dataset 6

Fig. 11. Plots for Test Dataset 1

Fig. 12. Plots for Test Dataset 2

Fig. 13. Plots for Test Dataset 3

Fig. 14. Plots for Test Dataset 4

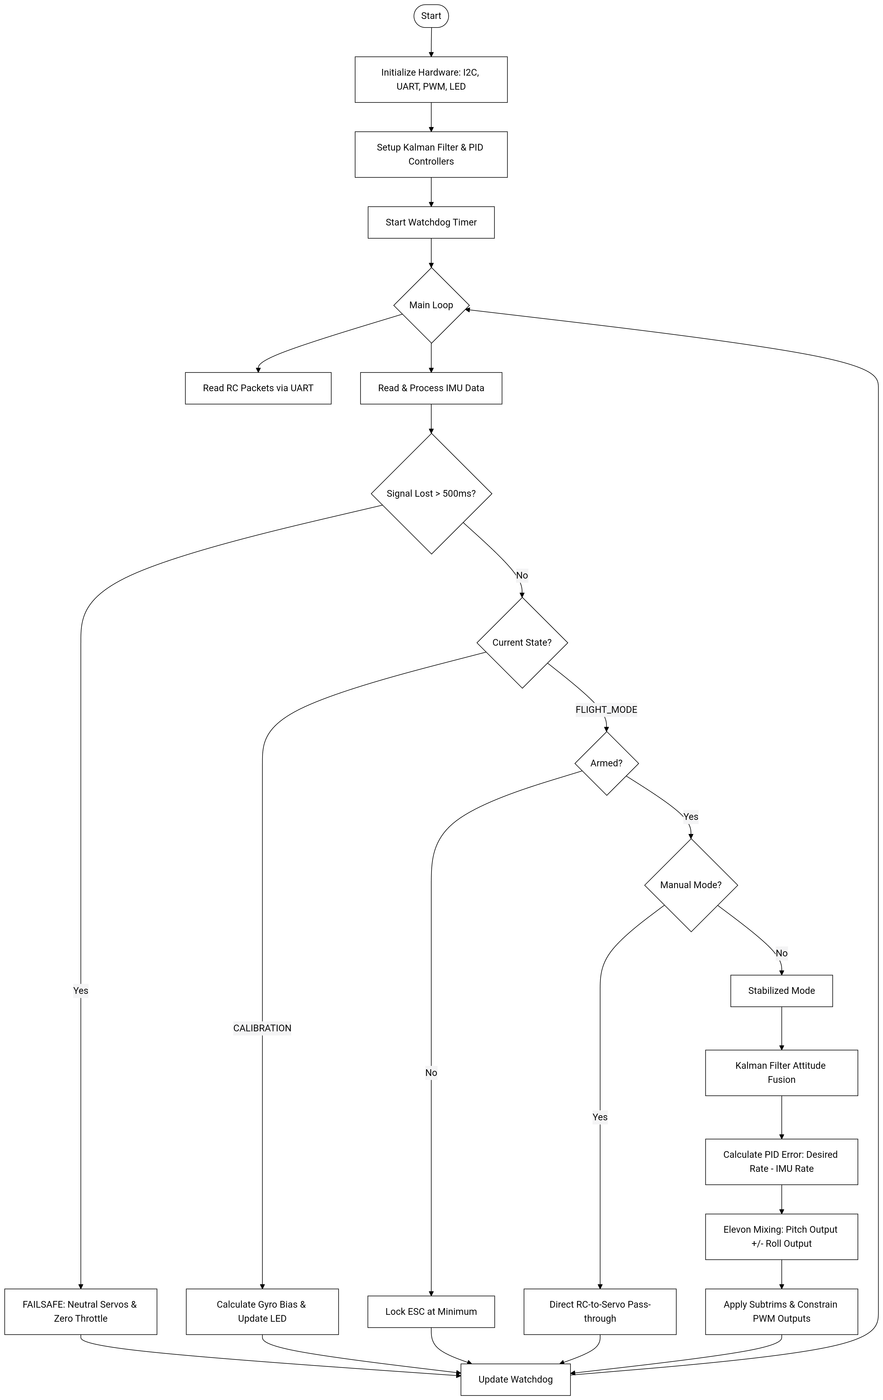
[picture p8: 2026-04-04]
firmware/docs/WingFC_Flowchart.png

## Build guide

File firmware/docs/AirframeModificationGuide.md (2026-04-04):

# **Modifying WingFC for Other Airframe Types**

Since WingFC handles sensor fusion and PID stabilization, the primary change required for different airframes is the **Mixer Logic**.

## **1. Traditional "T-Tail" Airplane**

**Difficulty: Low** Control surfaces are independent. You stop "mixing" signals on the same servos.

* **Logic Change:**  
  * CH1 PWM = rollOutput (Ailerons)  
  * CH2 PWM = pitchOutput (Elevator)  
  * *Optional:* Add a third PID controller for yawOutput (Rudder).  
* **Code Update:** Initialize a third PWM pin in the FC_Hardware struct and add a yawPID instance.

## **2. V-Tail Aircraft**

**Difficulty: Low** Mixes Pitch and Yaw on the rear surfaces, while Roll stays independent.

* **Logic Change:**  
  * Left V-tail = pitchOutput + yawOutput  
  * Right V-tail = pitchOutput - yawOutput  
  * Ailerons = rollOutput

## **3. Multirotors (Quadcopter)**

**Difficulty: Moderate to High** Motors provide both lift and attitude control.

* **Logic Change:** Each motor is a mix of Throttle + Pitch + Roll + Yaw.  
  * Front-Left = Throttle + Pitch + Roll + Yaw  
  * Front-Right = Throttle + Pitch - Roll - Yaw  
  * Rear-Left = Throttle - Pitch + Roll - Yaw  
  * Rear-Right = Throttle - Pitch - Roll + Yaw  
* **Hardware Challenge:** Requires 4 high-frequency (400Hz+) PWM outputs and a more robust disarm mechanism.

## **Technical Implementation Strategy**

To make WingFC modular, refactor the loop to use a generic **Mixer Function** or Interface:  
```Go
func ApplyMixer(pitch, roll, yaw, throttle float32) (outputs []float32) {  
    // Switch based on airframe config  
    // Return an array of PWM pulse widths  
}
```

### **Key Considerations**

* **PID Tuning:** Every airframe has a different "Moment of Inertia."  
* **Loop Timing:** 200Hz is great for wings; 400Hz+ is preferred for twitchy multirotors.  
* **Center of Gravity (CoG):** Hardware changes always require physical re-balancing.

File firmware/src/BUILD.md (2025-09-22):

# **WingFC Firmware Build Instructions**

This document outlines the steps required to build the WingFC firmware for different Radio Control (RC) protocols using TinyGo.

## **Prerequisites**

Before you begin, ensure you have the following tools installed and configured on your system:

* **Go:** The Go programming language, version 1.24 or later.  
* **TinyGo:** The TinyGo compiler, installed and set up for your target hardware.

## **Multi-Protocol Support**

The WingFC firmware supports multiple RC receiver protocols, specifically iBus and CRSF. Each protocol is implemented in a separate Go file (``ibus.go`` and ``crsf.go``) and uses a [Go build tag](https://www.google.com/search?q=https://pkg.go.dev/cmd/go%23hdr-Build_tags) to enable or disable its inclusion during compilation.

TinyGo allows for building and flashing through a single `flash` command
To build the firmware for a specific protocol, you must include the corresponding build tag in the tinygo `flash` command using the `-tags` flag.

## **Flash Commands**

Once your Xiao nrf52840 Sense is plugged in quickly press the reset button twice to connect the bootloader. 
The Xiao should show up as a USB device and is now ready to flash.
Use one of the following commands to build and flash the firmware for your desired protocol.

### **Flash for iBus Protocol**

This command compiles the firmware with iBus protocol support enabled.
```
tinygo flash -target=xiao-ble -tags=ibus .
```

### **Flash for CRSF Protocol**

This command compiles the firmware with CRSF protocol support enabled.
```
tinygo flash -target=xiao-ble -tags=crsf .
```

## **Build Commands**

To build the firmware for a specific protocol, you must include the corresponding build tag in the tinygo build command using the `-tags` flag.
Use one of the following commands to build the firmware for your desired protocol.

### **Build for iBus Protocol**

This command compiles the firmware with iBus protocol support enabled.
```
tinygo build -o wingfc-ibus.hex -target=xiao-ble -tags=ibus .
```

### **Build for CRSF Protocol**

This command compiles the firmware with CRSF protocol support enabled.
```
tinygo build -o wingfc-crsf.hex -target=xiao-ble -tags=crsf .
```

### **Explanation of Flags**

* `-o <filename>`: Specifies the output filename for the compiled firmware. We use a different name for each protocol for clarity.  
* `-target=<board>`: Specifies the target hardware board, the Xiao nrf52840 Sense.
* `-tags=<protocol>`: This is the critical flag for protocol selection. It tells the compiler which protocol file to include in the build.  
* `.`: The final dot indicates that the source code is in the current directory(WingFC/firmware/src).

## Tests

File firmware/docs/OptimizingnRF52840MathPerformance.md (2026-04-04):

# **WingFC Math Optimization Report**

**Target Hardware:** Seeed Studio XIAO nRF52840 Sense / Sense Plus (ARM Cortex-M4F)

## **Executive Summary**

The nRF52840 microcontroller features an ARM Cortex-M4F processor. The "F" denotes a hardware Floating-Point Unit (FPU), but crucially, **it only supports single-precision (float32) natively**.

Because Go defaults to float64, your current implementation forces the TinyGo compiler to inject software emulation for every float64 operation. This software emulation can take 10x to 50x more clock cycles than native instructions. By transitioning to float32 and fixed-point integer math, you will dramatically reduce control loop execution time, minimize latency, and free up cycles for other tasks like telemetry, logging, or LED management.

---

**Phase 1: The Single-Precision Downgrade (Highest ROI)**

The most immediate performance gain requires no algorithmic changes. We simply stop the hardware from emulating double-precision math.

### **1. Update Global Variables**

In main.go, redefine all floating-point globals explicitly as float32:

```Go
// main.go  
var (  
    // Force float32 for dt  
    dt float32 = 0.005 

    // IMU calibration - explicit float32  
    accelXSum, accelYSum, accelZSum, accelBiasX, accelBiasY, accelBiasZ float32 = 0., 0., 0., 0., 0., 0.  
    gyroXSum, gyroYSum, gyroZSum, gyroBiasX, gyroBiasY, gyroBiasZ       float32 = 0., 0., 0., 0., 0., 0.  
    desiredPitchRate, desiredRollRate                                   float32  
      
    leftServoSubtrim  float32 = LEFT_SERVO_SUBTRIM  
    rightServoSubtrim float32 = RIGHT_SERVO_SUBTRIM  
)
```

### **2. Update Constants**

In main.go, explicitly cast your math constants to float32 so they don't coerce your variables back to float64 during operations:

```Go
const (  
    microGToMS2    float32 = 9.80665 / 1e6  
    microDPSToRadS float32 = math.Pi / (180 * 1e6)  
    MAX_ROLL_RATE  float32 = MAX_ROLL_RATE_DEG * math.Pi / 180  
    MAX_PITCH_RATE float32 = MAX_PITCH_RATE_DEG * math.Pi / 180  
)
```

### **3. Update the PID Controller Struct**

In pid.go, downgrade the internal state to float32:

```Go
type PIDController struct {  
    Kp, Ki, Kd float32  
    prevError  float32  
    integral   float32  
}

func NewPIDController(Kp, Ki, Kd float32) *PIDController {  
    return &PIDController{Kp: Kp, Ki: Ki, Kd: Kd}  
}

func (pid *PIDController) Update(currentError, dt float32) float32 {  
    // Math remains exactly the same, but now runs natively on the FPU  
    // ...  
}
```

---

**Phase 2: Integer-Based Low-Pass Filter**

Floating-point multiplication in the IMU filter (helpers.go) is costly. Since the LSM6DS3TR gives you raw int16 values, you can filter them directly using fast bitwise shifts before doing any unit conversions.

### **The Bitwise LPF**

Instead of LPF_ALPHA = 0.2, we can use an alpha of 0.25 ($1/4$). Dividing by 4 is the same as a bitwise right-shift by 2 (>> 2), which executes in a single clock cycle.

```Go
// In helpers.go or main.go, track raw integers instead of floats  
var (  
    filteredAccelX, filteredAccelY, filteredAccelZ int32  
    filteredGyroX, filteredGyroY, filteredGyroZ int32  
)

func readLSMData() {  
    rawAccelX, rawAccelY, rawAccelZ, _ := hw.IMU.ReadAccel()  
    rawGyroX, rawGyroY, rawGyroZ, _ := hw.IMU.ReadGyro()

    // Fast Integer LPF (Alpha ~0.25)  
    filteredAccelX = filteredAccelX - (filteredAccelX >> 2) + (int32(rawAccelX) >> 2)  
    filteredAccelY = filteredAccelY - (filteredAccelY >> 2) + (int32(rawAccelY) >> 2)  
    filteredAccelZ = filteredAccelZ - (filteredAccelZ >> 2) + (int32(rawAccelZ) >> 2)  
      
    filteredGyroX = filteredGyroX - (filteredGyroX >> 2) + (int32(rawGyroX) >> 2)  
    filteredGyroY = filteredGyroY - (filteredGyroY >> 2) + (int32(rawGyroY) >> 2)  
    filteredGyroZ = filteredGyroZ - (filteredGyroZ >> 2) + (int32(rawGyroZ) >> 2)  
      
    // Only convert to float32 at the very end when feeding the Kalman filter or PID  
    imuData.AccelX = float32(filteredAccelX) * microGToMS2  
    // ... etc  
}
```

---

**Phase 3: Optimizing RC Input Mapping**

Currently, mapRange takes float64 inputs. Since your RC channels come in as uint16 (988 to 2012), mapping them to control targets shouldn't require floating-point math.

### **Integer Mapping Function**

Create a dedicated mapRangeInt in helpers.go:

```Go
// Pure integer math: no FPU required  
func mapRangeInt(value, fromMin, fromMax, toMin, toMax int32) int32 {  
    return (value - fromMin) * (toMax - toMin) / (fromMax - fromMin) + toMin  
}
```

When you calculate desiredPitchRate and desiredRollRate in main.go, do it in integer space first (e.g., mapping 1000-2000 to -200 to +200 degrees/sec), and only convert to float32 radians per second when subtracting from the gyro error.

---

**Phase 4: Fixed-Point PID Implementation (Optional, Advanced)**

If you want to squeeze out every last cycle, you can replace the FPU entirely in your control loop by scaling your PID parameters and doing everything in int32.

Instead of Kp = 1.0, you use Kp = 1000. You perform your math, and then divide the final output by 1000.

```Go
const PID_SCALE int32 = 1024 // 1024 is better than 1000 because division is a bitshift (>> 10)

type IntPIDController struct {  
    Kp, Ki, Kd int32   
    prevError  int32   
    integral   int32   
}

// dt is now passed as milliseconds (e.g., 5 for 200Hz) instead of 0.005 seconds  
func (pid *IntPIDController) Update(currentError int32, dtMs int32) int32 {  
    proportional := (pid.Kp * currentError) >> 10

    pid.integral += currentError * dtMs  
    integral := (pid.Ki * pid.integral) >> 10

    derivative := (pid.Kd * (currentError - pid.prevError) / dtMs) >> 10  
    pid.prevError = currentError

    return proportional + integral + derivative  
}
```

*Note: While highly efficient, tuning a fixed-point PID requires you to re-evaluate your base PID numbers. Only implement this if float32 proves too slow (unlikely on the M4F).*

## **Summary of Recommendations**

1. **Mandatory:** Change all float64 types and constants to float32. The M4F handles single-precision natively, providing an immediate speedup.  
2. **Highly Recommended:** Implement the integer-based LPF using bitwise shifts. It's computationally "free."  
3. **Highly Recommended:** Strip floats out of the RC channel mapRange functions.  
4. **Evaluate Later:** Fixed-point PID. The M4F's hardware FPU should be fast enough to handle float32 PID loops comfortably at 200Hz, making full fixed-point math optional rather than strictly necessary.

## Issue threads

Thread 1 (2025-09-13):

Eventual repo structure

BryanSouza91, 2025-09-13:
WingFC/
├── hardware/
│   ├── kicad/
│   │   ├── WingFC.kicad_sch
│   │   ├── WingFC.kicad_pcb
│   │   ├── WingFC.kicad_pro
│   │   ├── libs/ (for project-specific symbols, footprints, 3D models)
│   │   └── gerbers/ (for generated production files)
│   └── docs/ (for datasheets, assembly instructions, etc. related to hardware)
├── firmware/
│   ├── src/ (source code for embedded software)
│   ├── include/ (header files)
│   ├── lib/ (external libraries)
│   └── build/ (build artifacts, if applicable)
├── software/ (for host-side applications, scripts, etc.)
│   ├── src/
│   └── docs/
├── documentation/ (for overall project documentation, user manuals)
├── CONTRIBUTING.md
├── LICENSE
└── README.md

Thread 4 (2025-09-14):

Support Building WingFC for Multiple Hardware Targets

BryanSouza91, 2025-09-14:
I’d like to improve WingFC’s build system to support compiling for different hardware targets (e.g., Seeed Studio Xiao nRF52840, Xiao ESP32, other MCUs supported by TinyGo). The goal is to make it easy for users to select their board and build the firmware accordingly.

### Requirements:
Allow selection of target board via build flag, environment variable, or config file.
Ensure hardware-specific code (e.g., pin mappings, peripherals) is abstracted or conditionally compiled.
Update documentation to explain how to build for each supported target.
Provide example configs or scripts for common boards.

### Motivation:
Supporting multiple targets will make WingFC more accessible and flexible for the community, and allow easier testing and development on different hardware.

### Possible Approaches:

- Use TinyGo’s -target flag and document supported boards.
- Refactor hardware-dependent code using build tags or interfaces.
- Add board-specific config files for pin mappings and peripherals.

For the time being I will move all the configurable parameters to config.go for simplicity.

#### Additional Context:
Current code is tailored for Xiao nRF52840. See [main.go](https://github.com/BryanSouza91/WingFC/tree/main/firmware/src/main.go) and related files for hardware-specific logic.

BryanSouza91, 2025-09-20:
This would be best accomplished through the use of the `tinygo -target` build flag. Target specific code that can be moved to target specific files should be moved any code that cannot or should not be moved to a target specific file should be made agnostic to target and targets configured accordingly.

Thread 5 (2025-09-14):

Add GPS Support

BryanSouza91, 2025-09-14:
I’d like to add GPS functionality to WingFC, enabling features such as altitude hold, return-to-home, and telemetry. The Adafruit Ultimate GPS (Product 4415) is a good reference module for lightweight and I2C support, but support should be flexible for similar serial GPS devices.

### Requirements:
Integrate GPS parsing (NMEA sentences) via UART or other supported interfaces.
Abstract GPS handling so other modules can use position, speed, altitude, and fix status.
Add configuration options for GPS baud rate and port.
Update documentation with wiring instructions and usage examples.
Add basic GPS-based features (e.g., logging, telemetry output, failsafe enhancements).

### Motivation:
GPS support will enable advanced flight features and improve safety for autonomous and long-range flights.

### Possible Approaches:
- Use or adapt an existing TinyGo/Go GPS library for NMEA parsing.
- Add a GPS module (e.g., gps.go) and integrate with the main control loop.
- Provide example code and documentation for connecting and configuring the Adafruit Ultimate GPS.

### Additional Context:
#### Reference:
[Adafruit Ultimate GPS - Product 4415](https://www.adafruit.com/product/4415)

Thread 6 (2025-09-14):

Integrate ELRS/CRSF Receiver and WingFC with TinyGo ESP32 Dual-Core Support

BryanSouza91, 2025-09-14:
When TinyGo adds support for dual-core operation on the ESP32, I’d like to explore integrating the ELRS/CRSF receiver directly into WingFC for an all-in-one receiver and flight controller solution.

### Requirements:
- Use one core for real-time flight control and the other for receiver protocol handling (ELRS/CRSF).
- Ensure reliable, low-latency communication between cores.
- Abstract receiver and flight control logic for modularity.
- Update documentation and configuration for ESP32 dual-core builds.

### Motivation:
This would enable a compact, high-performance flight controller with integrated receiver, reducing wiring and improving reliability for ESP32-based aircraft.

### Possible Approaches:
- Monitor TinyGo’s ESP32 dual-core support progress.
- Design modular code to separate receiver and flight control tasks.
- Implement inter-core communication (e.g., shared memory, message passing).

### Additional Context:
ESP32 is widely used in DIY RC and drone projects.
ELRS/CRSF integration would make WingFC more versatile and attractive for advanced users.

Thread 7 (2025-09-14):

Add WiFi and Bluetooth Configuration Support to WingFC

BryanSouza91, 2025-09-14:
I’d like to add support for configuring WingFC via WiFi and/or Bluetooth. This would allow users to set parameters, update firmware, and possibly monitor telemetry from a mobile device or computer.

### Requirements:
- Implement a configuration interface accessible over WiFi and/or Bluetooth.
- Allow users to change flight parameters, receiver protocol, and other settings remotely.
- Support secure firmware updates via wireless connection.
- Provide real-time telemetry streaming (optional).
- Update documentation with setup and usage instructions.

### Motivation:
Wireless configuration and telemetry will make WingFC easier to use, especially for field adjustments and diagnostics, and will modernize the user experience.

### Possible Approaches:
- Use TinyGo’s networking and Bluetooth libraries (as available).
- Design a simple web or app-based UI for configuration.
- Implement a secure protocol for firmware updates and settings changes.

### Additional Context:
- Many modern flight controllers support wireless configuration.
- nrf52840, ESP32 and similar MCUs have built-in WiFi/Bluetooth hardware.

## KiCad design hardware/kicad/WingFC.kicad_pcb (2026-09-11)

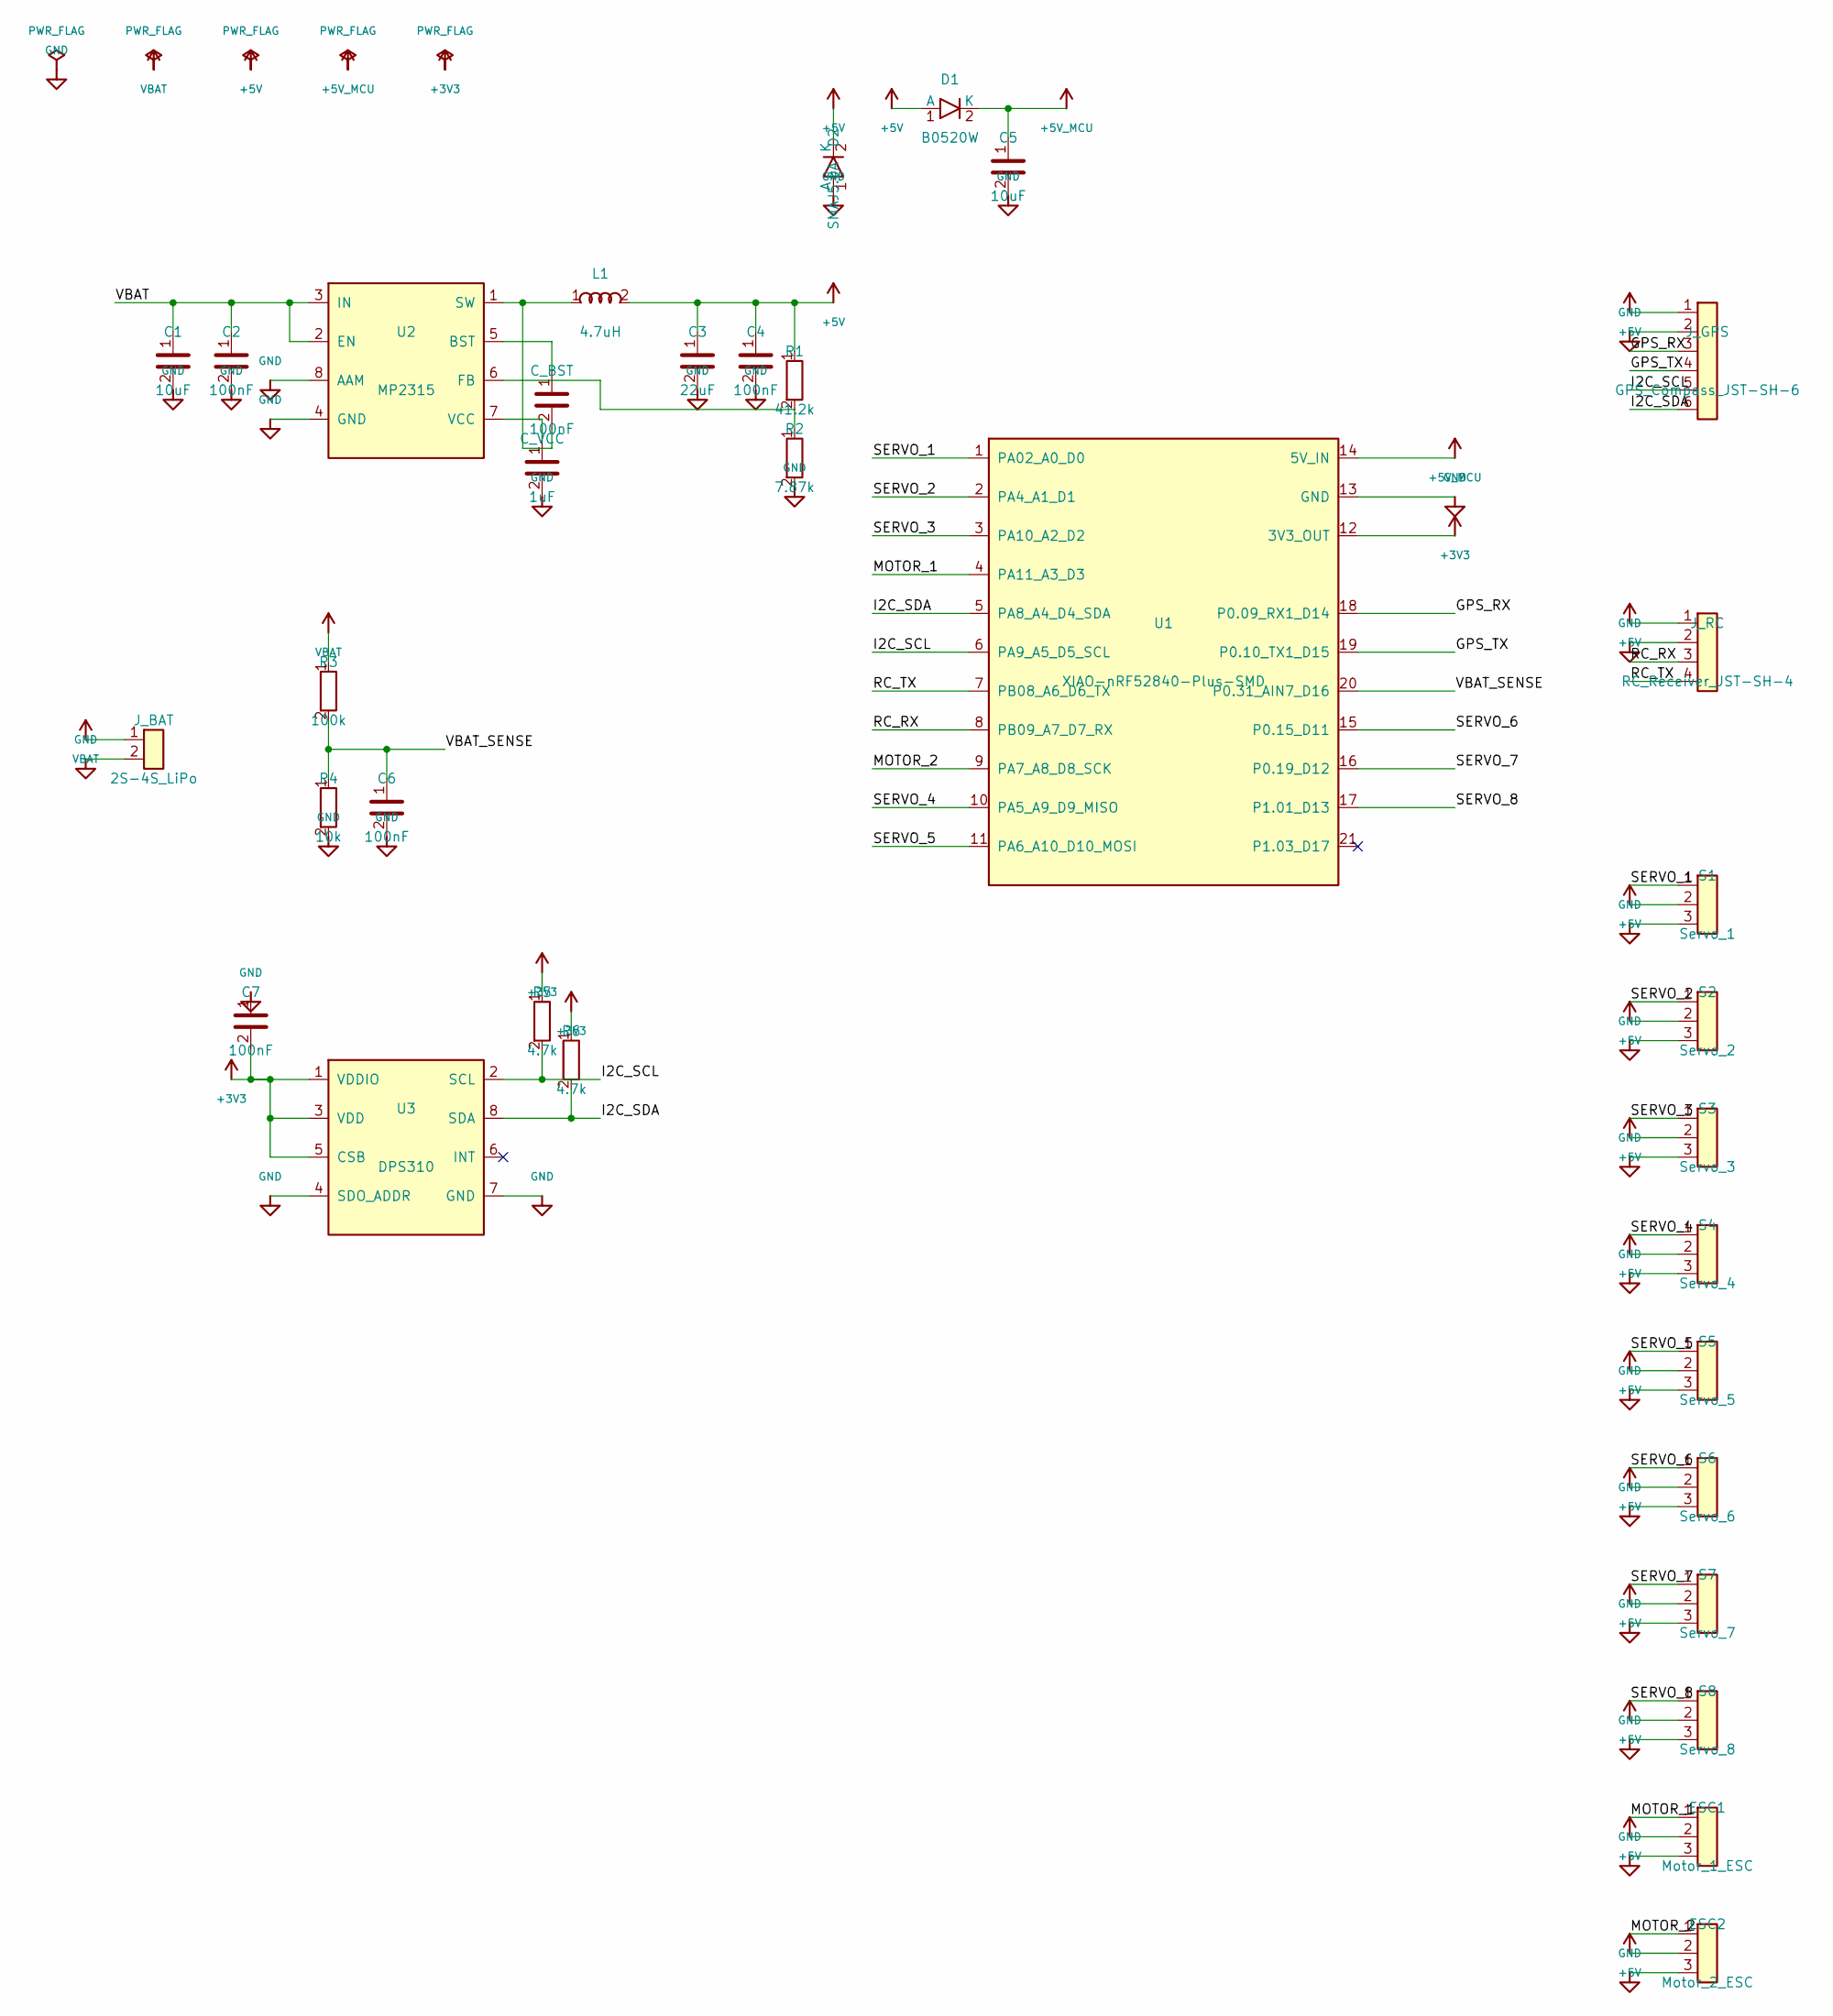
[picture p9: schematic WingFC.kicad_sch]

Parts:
C1, C5: 10uF; C_0805_2012Metric
C2, C4, C6, C7: 100nF; C_0603_1608Metric
C3: 22uF; C_0805_2012Metric
C_BST: 100nF; C_0603_1608Metric
C_VCC: 1uF; C_0603_1608Metric
D1: B0520W; D_SOD-123
D2: SMAJ5.0A; D_SMA
ESC1: Motor_1_ESC; PinHeader_1x03_P2.54mm_Vertical
ESC2: Motor_2_ESC; PinHeader_1x03_P2.54mm_Vertical
J_BAT: 2S-4S_LiPo; SolderWire-0.75sqmm_1x02_P4.8mm_D1.2mm_OD2.3mm
J_GPS: GPS_Compass_JST-SH-6; JST_SH_SM06B-SRSS-TB_1x06-1MP_P1.00mm_Horizontal
J_RC: RC_Receiver_JST-SH-4; JST_SH_SM04B-SRSS-TB_1x04-1MP_P1.00mm_Horizontal
L1: 4.7uH; L_Bourns_SRN4018
R1: 41.2k; R_0603_1608Metric
R2: 7.87k; R_0603_1608Metric
R3: 100k; R_0603_1608Metric
R4: 10k; R_0603_1608Metric
R5, R6: 4.7k; R_0603_1608Metric
S1: Servo_1; PinHeader_1x03_P2.54mm_Vertical
S2: Servo_2; PinHeader_1x03_P2.54mm_Vertical
S3: Servo_3; PinHeader_1x03_P2.54mm_Vertical
S4: Servo_4; PinHeader_1x03_P2.54mm_Vertical
S5: Servo_5; PinHeader_1x03_P2.54mm_Vertical
S6: Servo_6; PinHeader_1x03_P2.54mm_Vertical
S7: Servo_7; PinHeader_1x03_P2.54mm_Vertical
S8: Servo_8; PinHeader_1x03_P2.54mm_Vertical
U1: XIAO-nRF52840-Plus-SMD
U2: MP2315; TSOT-23-8
U3: DPS310; Infineon_PG-VLGA-8-1_2.0x2.5mm_P0.65mm

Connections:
+3V3: C7.2, R5.1, R6.1, U1.12 (3V3_OUT), U3.1 (VDDIO), U3.3 (VDD), U3.5 (CSB)
+5V: C3.1, C4.1, D1.1 (A), D2.2 (K), ESC1.2, ESC2.2, J_GPS.1, J_RC.1, L1.2, R1.1, S1.2, S2.2, S3.2, S4.2, S5.2, S6.2, S7.2, S8.2
+5V_MCU: C5.1, D1.2 (K), U1.14 (5V_IN)
/GPS_RX: J_GPS.3, U1.18 (P0.09_RX1_D14)
/GPS_TX: J_GPS.4, U1.19 (P0.10_TX1_D15)
/I2C_SCL: J_GPS.5, R5.2, U1.6 (PA9_A5_D5_SCL), U3.2 (SCL)
/I2C_SDA: J_GPS.6, R6.2, U1.5 (PA8_A4_D4_SDA), U3.8 (SDA)
/MOTOR_1: ESC1.1, U1.4 (PA11_A3_D3)
/MOTOR_2: ESC2.1, U1.9 (PA7_A8_D8_SCK)
/RC_RX: J_RC.3, U1.8 (PB09_A7_D7_RX)
/RC_TX: J_RC.4, U1.7 (PB08_A6_D6_TX)
/SERVO_1: S1.1, U1.1 (PA02_A0_D0)
/SERVO_2: S2.1, U1.2 (PA4_A1_D1)
/SERVO_3: S3.1, U1.3 (PA10_A2_D2)
/SERVO_4: S4.1, U1.10 (PA5_A9_D9_MISO)
/SERVO_5: S5.1, U1.11 (PA6_A10_D10_MOSI)
/SERVO_6: S6.1, U1.15 (P0.15_D11)
/SERVO_7: S7.1, U1.16 (P0.19_D12)
/SERVO_8: S8.1, U1.17 (P1.01_D13)
/VBAT_SENSE: C6.1, R3.2, R4.1, U1.20 (P0.31_AIN7_D16)
GND: C1.2, C2.2, C3.2, C4.2, C5.2, C6.2, C7.1, C_VCC.2, D2.1 (A), ESC1.3, ESC2.3, J_BAT.2, J_GPS.2, J_RC.2, R2.2, R4.2, S1.3, S2.3, S3.3, S4.3, S5.3, S6.3, S7.3, S8.3, U1.13 (GND), U2.4 (GND), U2.8 (AAM), U3.4 (SDO_ADDR), U3.7 (GND)
unnamed: C_BST.1, U2.5 (BST)
unnamed: R1.2, R2.1, U2.6 (FB)
unnamed: C_BST.2, L1.1, U2.1 (SW)
unnamed: C_VCC.1, U2.7 (VCC)
VBAT: C1.1, C2.1, J_BAT.1, R3.1, U2.2 (EN), U2.3 (IN)

Board: 4 copper layers, 38 parts (21 on the bottom side), 26 nets, no tracks yet.

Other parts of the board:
H1, H2, H3, H4: MountingHole_2.2mm_M2

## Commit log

2025-09-11 added missing logic for throttle control; added adjustable constants for configuration;
2025-09-11 fixed error of units between degs and rads for roll and pitch rates; added .gitignore;
2025-09-12 restructured directory and file nomenclature;
    [WingFC.kicad_pcb, WingFC.kicad_sch]
2025-09-13 fixed logic of switch breakout between states based on conditions;
2025-09-13 updated comment in CALIBRATING state;
2025-09-15 worked on PCB design;
    [WingFC.kicad_pcb, WingFC.kicad_sch]
2025-09-15 removed kicad backups;
2025-09-16 converted to 4-layer PCB;
    [WingFC.kicad_pcb, WingFC.kicad_sch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]
2025-09-16 fixed small error on PCB;
    [WingFC.kicad_pcb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]
2025-09-19 Added EMA Low-Pass Filter on IMU in hopes to help with drift and inaccuracies;
2025-09-21 fixed bug with receiver packet processing for iBus; fixed PWM high freq signal issue;
2025-09-22 fixed calibration issue;
2025-09-24 reformatted printed message for crsf test;
2025-09-25 added delay for buffering data from uart for debugging;
2025-09-26 adjusted CALIBRATION state;
2025-09-26 more debugging printing;
2026-03-10 Add manual mode config and processing with pid reset.
2026-03-10 Fix pid reset to actually reset the pid controllers
2026-03-10 Added 8 color LED helper. Added boot check/err LED indicators to main.
2026-03-30 Copy LED changes from dev-subtrim-led to dev-init.
2026-04-03 updated LED system to use the same dependency injection methods; added DigitalPin interface;
2026-04-03 updated matrix and kalman for 3x3 matrix compatibility; updated main loop to 200Hz as a major performance boost;
2026-04-03 fixed disarm mode, now only ESC is disarmed; added documentation to pid.go for unit continuity refer to UNIT_ANALYSIS.md;
2026-04-04 removed duplicate PWM adapter;
2026-04-04 adding Flowchart and a few other documents;
2026-04-04 adding Flowchart mermaid.js file;
2026-04-05 converted Low-Pass Filter to single cycle bitshift operation from math operation;
2026-04-05 added variable declarations for Low-Pass Filter;
2026-04-05 added more tuning parameters; added board orientation support;
2026-04-05 corrected calibration with correct applications of the filters and orientation;
2026-04-11 moved call to initPWMs to be earliest; addressed the ESC initialization error with initPWM Set call;
2026-04-11 added No Motion No Integration (NMNI) algorithm for Yaw; Double checked units and corrected as necessary;
2026-04-11 added absolute value calc to NMNI filter;
2026-04-11 added some IMU related documents;
2026-09-11 Update KiCad schematic, PCB layout, and footprints for WingFC
    [WingFC-old.kicad_sch, WingFC.kicad_pcb, WingFC.kicad_sch]
2026-09-26 chore(kicad): Register top-level schematic in WingFC.kicad_pro
